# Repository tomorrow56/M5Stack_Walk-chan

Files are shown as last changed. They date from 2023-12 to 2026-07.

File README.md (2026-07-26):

# M5Stack_Walk-chan

A bipedal robot built with M5Stack.

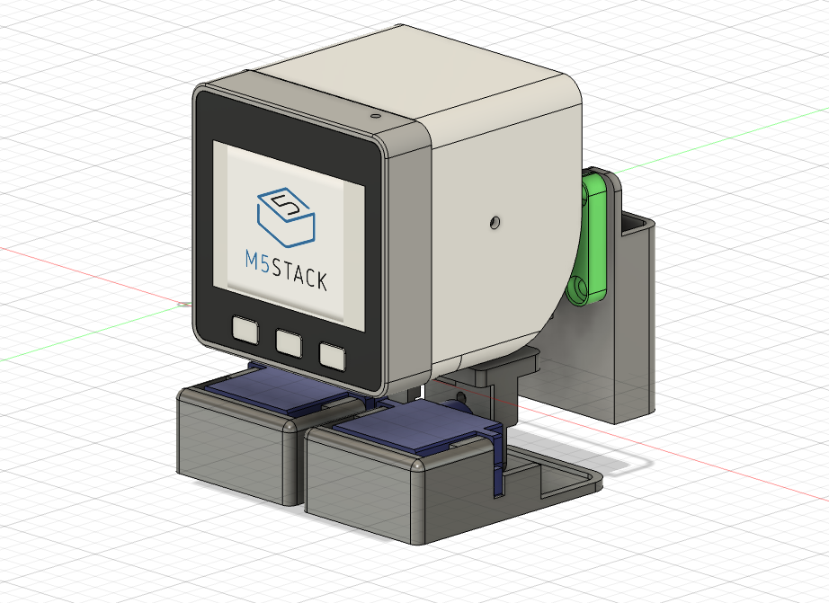
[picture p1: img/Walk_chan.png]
Walk-chan


## Overview

M5Stack Walk-chan（以下、Walk-chan）は、M5Stack を制御ボードとして使った2足歩行ロボットです。Otto DIY のような小型2足歩行ロボットを M5Stack サイズで実現することを目指し、2022年の「ｽﾀｯｸﾁｬﾝ（Stack-chan）」誕生1周年の誕生日会にあわせて設計されました。

このタイプの2足歩行ロボットで重要となるのは、片足を上げた際に接地している足側へ重心を確実に移すことです。M5Stack 本体だけでは重心移動が不十分なため、背面に搭載したバッテリーを左右に動かす直動機構を追加しています。これにより、安定した歩行動作を実現しています。

詳細な制作背景や動作動画については、note 記事「[二足歩行ｽﾀｯｸﾁｬﾝ(Walk chan)を作ってみた](https://note.com/tomorrow56/n/nf83f81b76e1e)」を参照してください。

## Features

- M5Stack 搭載の2足歩行ロボット
- 重心移動用のバッテリー直動機構（ラック＆ピニオン）
- サーボモータ SG90 を計5個使用
- M5Stack の M-Bus からサーボ PWM 用コネクタへ変換する基板同梱
- 3D プリント用 STL ファイルとアセンブリ済み STEP 形式のボディデータ
- Arduino IDE / PlatformIO 向けサンプルスケッチ
- LCD 上にアバター（目）を表示し、歩行と連動した演出が可能

## Hardware

### Required Parts

| 部品 | 数量 | 備考 |
|---|---|---|
| M5Stack Basic / Gray / Fire など | 1 | 制御ボード |
| SG90 互換サーボ | 5 | 2足（脚・足首）+ バッテリー移動用 |
| M5Stack Walk-chan 用基板 | 1 | 本リポジトリの `pcb/` 参照 |
| 3D プリント部品 | 一式 | `3Ddata/stl/` を参照 |
| リチウムイオン電池（NP-40 等） | 1 | コンパクトデジカメ用バッテリー推奨 |
| M3 ビス・ナット | 適量 | ギアガイドなどに使用 |

### Servo Assignment

サンプルスケッチでは、以下のように GPIO とサーボを割り当てています。

| サーボ | GPIO | LEDC チャンネル | 役割 |
|---|---|---|---|
| FootR  | 2 | 0 | 右足首（左右傾き） |
| FootL  | 12 | 1 | 左足首（左右傾き） |
| LegR | 0 | 2 | 右脚（前後スイング） |
| LegL | 15 | 3 | 左脚（前後スイング） |
| Ballast| 13 | 4 | バッテリー重心移動 |

サーボの中心位置や可動範囲は、個体差や組み立て状態に応じてスケッチ内の `cent*` 定数や `rot*` 定数を調整してください。

## 3D Model

ボディ部品の 3D データは `3Ddata/` に格納されています。

- `Walk-chan_assembled.step`：アセンブリ済みの STEP 形式ファイル（Fusion360 などで編集可能）
- `stl/`：3D プリント用の分割 STL ファイル
  - `bracket_front.stl`, `bracket_rear.stl`：前後ブラケット
  - `foot_l.stl`, `foot_r.stl`：左右の足
  - `joint_l.stl`, `joint_r.stl`：左右の脚関節
  - `gear.stl`, `rack_gear.stl`, `gear_guide.stl`：バッテリー直動機構用ギア
  - `holder_NP-40.stl`：NP-40 バッテリーホルダー
  - `shell.stl`：外装シェル

**注意：** 組み立て手順書は作成に至っていないため、現状ではアセンブリ済みの STEP ファイルを CAD で確認しながら組み立ててください。各部品の干渉やサーボの取り付け方向に注意してください。

## PCB for SG90

M5Stack の M-Bus からサーボ用 PWM コネクタに変換する基板データを `pcb/` に同梱しています。

- [gerber](pcb/gerver/)
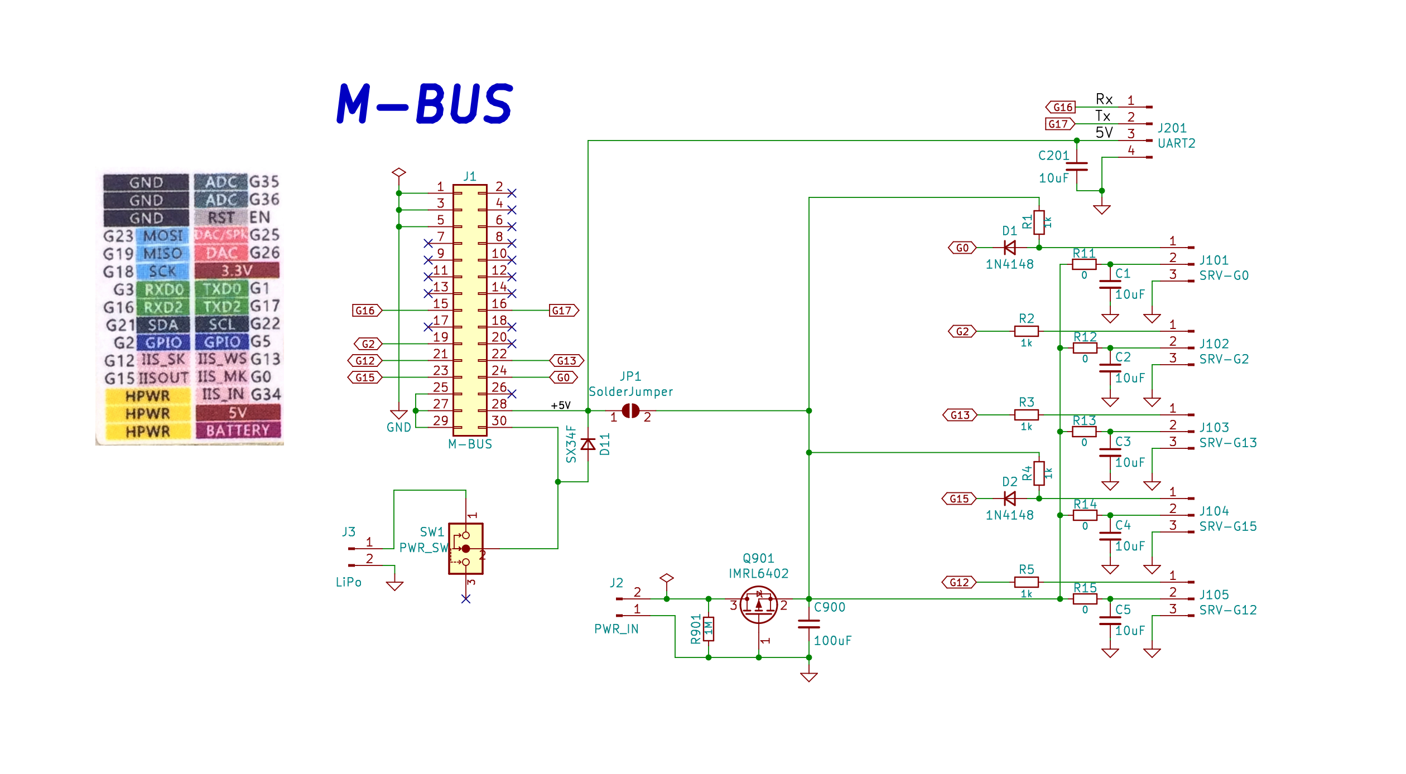
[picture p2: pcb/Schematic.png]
Schematic
- 

### 基板の主な仕様

- M5Stack の M-Bus コネクタから直接各サーボの PWM 信号を出力
- サーボ制御 IC は使用せず、M5Stack の GPIO / LEDC 出力で直接駆動
- Grove 互換コネクタを引き出し、外部センサー等の拡張が可能
- サーボ電源は「コネクタから供給」または「M-Bus の 5V から供給」をハンダジャンパで選択可能
- 2pin ピンヘッダで「サーボ用 5V 電源」と「M5Stack 用リチウムイオン電池」を接続可能
- 横面の物理スイッチで M5Stack 本体の電源 ON/OFF が可能

## Sample Code

サンプルスケッチは `examples/M5_walk-chan_WalkTest/` に格納されています。

- `M5_walk-chan_WalkTest.ino`：メインスケッチ。歩行シーケンスとアバター表示、電池残量・充電状態の監視を行います。
- `clappyavator.h` / `clappyavator.cpp`：M5Stack の LCD に表示するアバター（目）を描画するライブラリ。
- `ip5306.h`：M5Stack 内蔵の電源管理 IC（IP5306）のレジスタ定義。

### 歩行シーケンスの概要

1. バラスト（バッテリー）を左右に移動し、重心を支持脚側へ移す。
2. 支持脚側の足首を内側・遊脚側の足首を外側に傾け、体を傾ける。
3. 遊脚の脚を前後に振り出す。
4. 足首を元に戻し、遊脚を地面に降ろす。
5. 反対側も同様に繰り返し、歩行を継続する。

`setup()` 内では上記の初期動作を1サイクル実施した後、`loop()` 内で左右交互に歩行動作を繰り返します。

### 充電モード

電源投入時に IP5306（0x75）が検出され、かつ充電中の場合は「HOME POSITION」調整モードに移行します。ボタン B を押すと通常の歩行デモに切り替わります。充電中にサーボが動作すると電源負荷や動作不安定の原因になるため、この安全機能が入っています。

## Build and Flash

1. 必要な部品を用意し、3D プリント部品を印刷します。
2. STEP ファイルまたは STL ファイルを参考に、サーボ・ギア・バッテリーを組み込みます。
3. 基板を製造・はんだ付けし、M5Stack と各サーボを接続します。
4. Arduino IDE または PlatformIO で `M5_walk-chan_WalkTest` を開き、M5Stack 向けにビルド・書き込みします。
   - 必要ライブラリ：`M5Stack` ライブラリ
5. 電源を入れ、M5Stack の LCD にアバターが表示され、Walk-chan が歩き始めることを確認します。

## Notes

- 基板のサーボコネクタはブラケットと干渉しない位置に配置されています。コネクタの向きに注意して配線してください。
- バッテリーケースはラックギヤにビスで固定されています。現在は NP-40 型のリチウムイオン電池用ホルダーが同梱されていますが、ケースを差し替えることで単4 乾電池など他の電源にも置き換え可能です。
- バッテリーの左右移動機構はブラケットにはめ込んだ交換可能な構造になっています。
- 2足歩行ロボットのため、床面やバランスによっては転倒することがあります。初動作時は周囲に十分なスペースをとり、低速で確認してください。

## References

- [note: 二足歩行ｽﾀｯｸﾁｬﾝ(Walk chan)を作ってみた](https://note.com/tomorrow56/n/nf83f81b76e1e)
- [Printables: M5Stack Walk-chan](https://www.printables.com/model/687241-m5stack-walk-chan)
- [tomorrow56 (ThousanDIY)](https://note.com/tomorrow56)

## License

[MIT License](LICENSE)

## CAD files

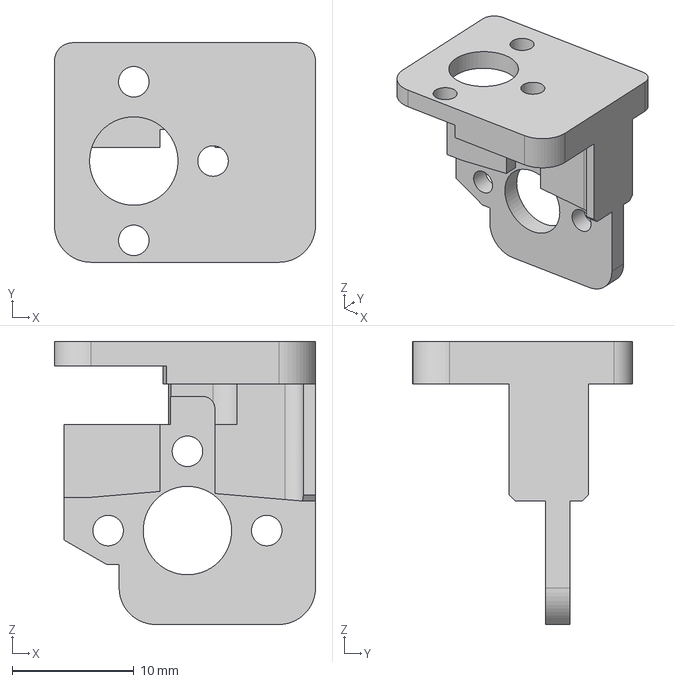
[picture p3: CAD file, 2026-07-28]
3Ddata/step/Joint-L.step
21.4 x 18.0 x 23.2 mm

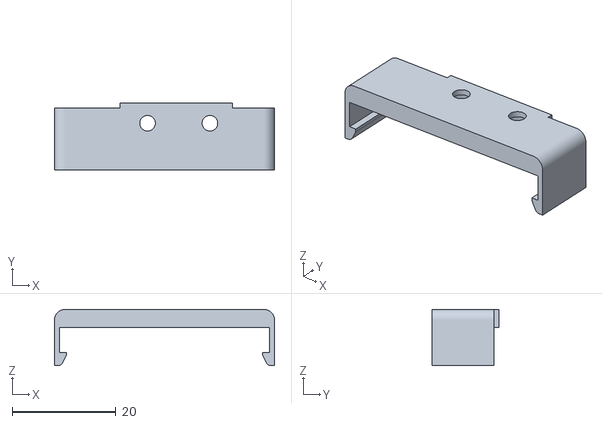
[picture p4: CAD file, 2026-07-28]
3Ddata/stl/Guide.stl
42.3 x 12.9 x 10.8

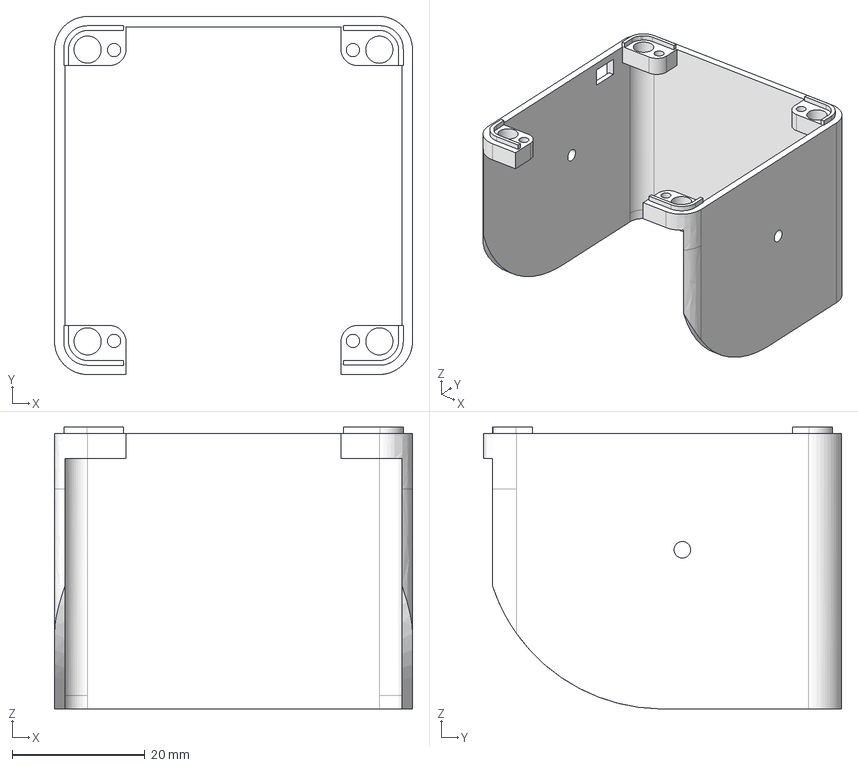
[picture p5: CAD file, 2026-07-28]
3Ddata/step/shell.step
54.0 x 54.0 x 42.5 mm

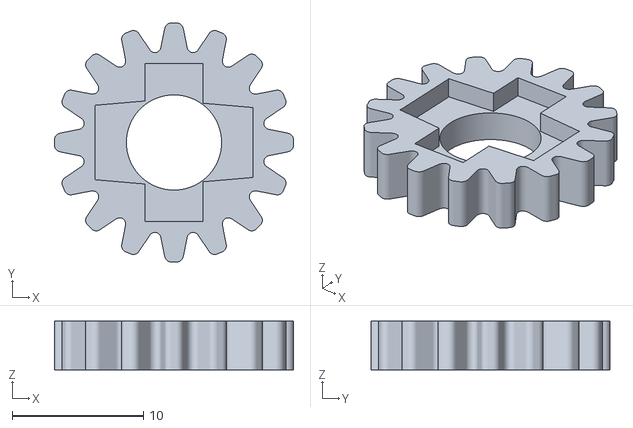
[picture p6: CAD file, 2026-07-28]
3Ddata/stl/gear.stl
18.2 x 18.2 x 3.70

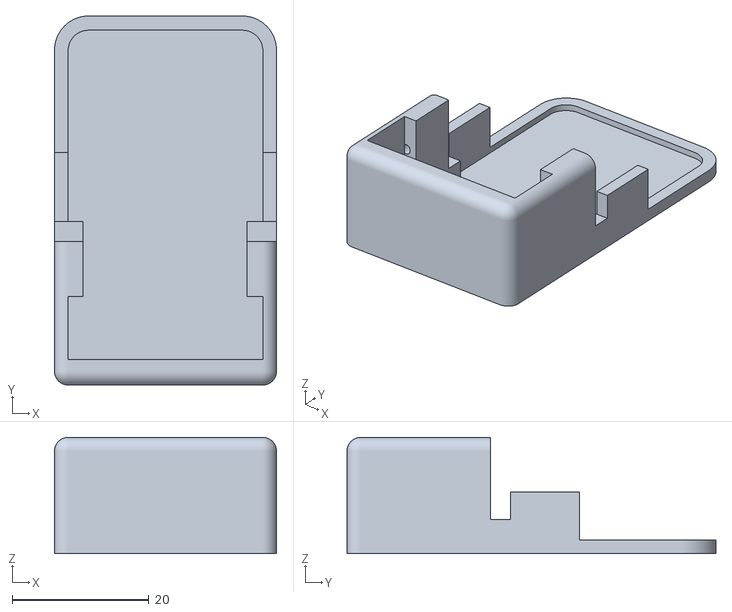
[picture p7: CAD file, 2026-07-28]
3Ddata/stl/foot_1.stl
32.5 x 54.0 x 17.0

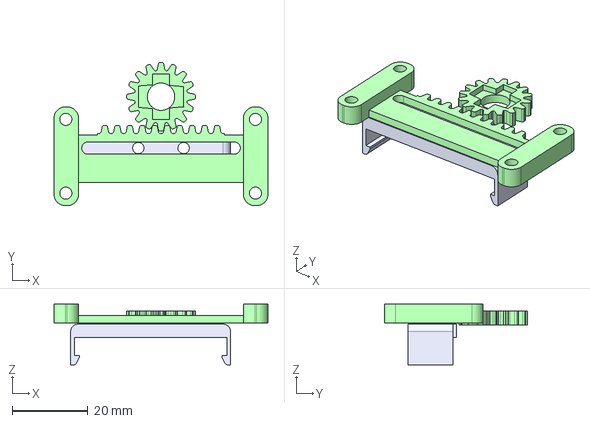
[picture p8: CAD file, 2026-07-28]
3Ddata/step/Servo_Linear.step
56.6 x 38.0 x 16.1 mm

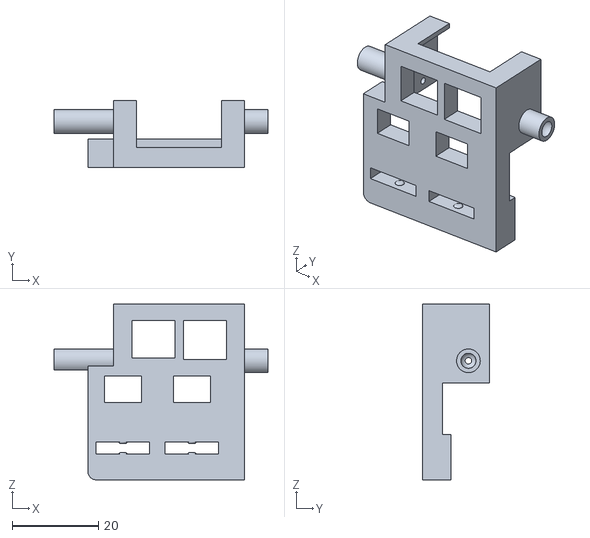
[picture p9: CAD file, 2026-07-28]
3Ddata/stl/bracket_front.stl
49.6 x 15.7 x 40.8

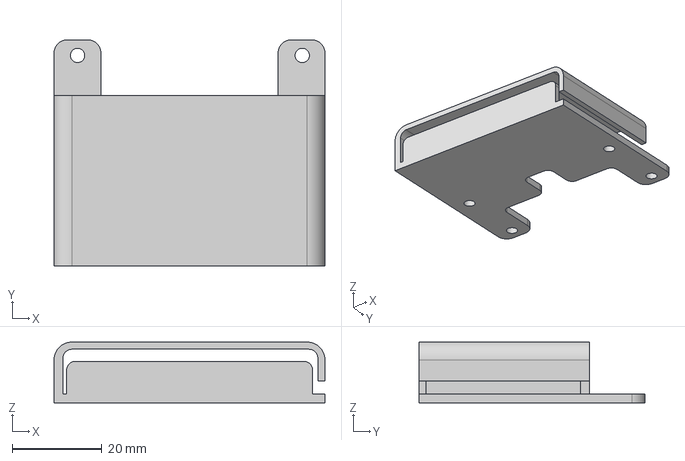
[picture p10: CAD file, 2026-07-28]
3Ddata/step/holder_NP-40.step
60.6 x 50.6 x 13.6 mm

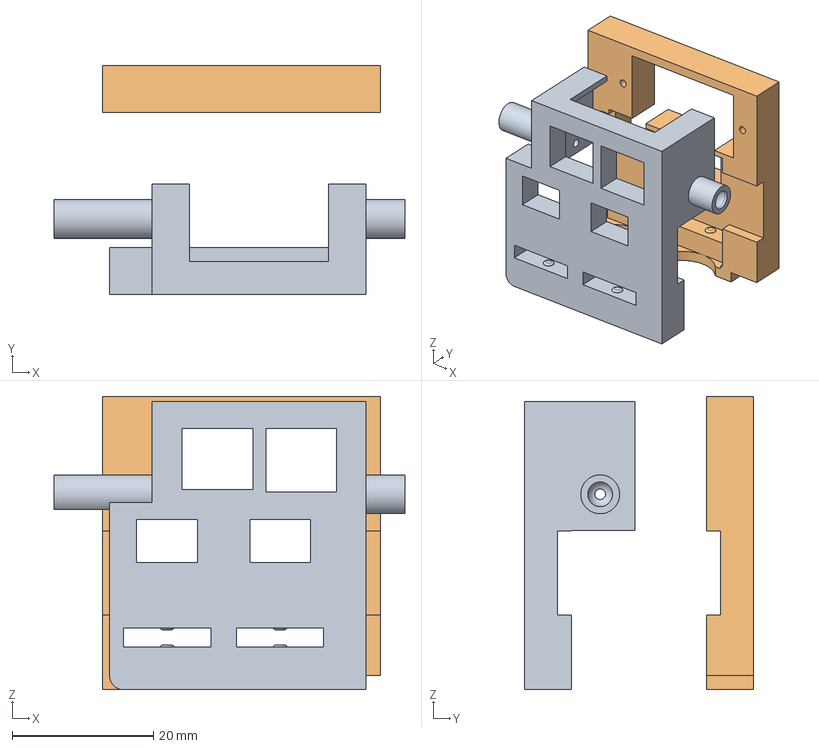
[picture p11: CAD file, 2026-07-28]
3Ddata/step/bracket_SG90.step
49.7 x 32.4 x 41.5 mm

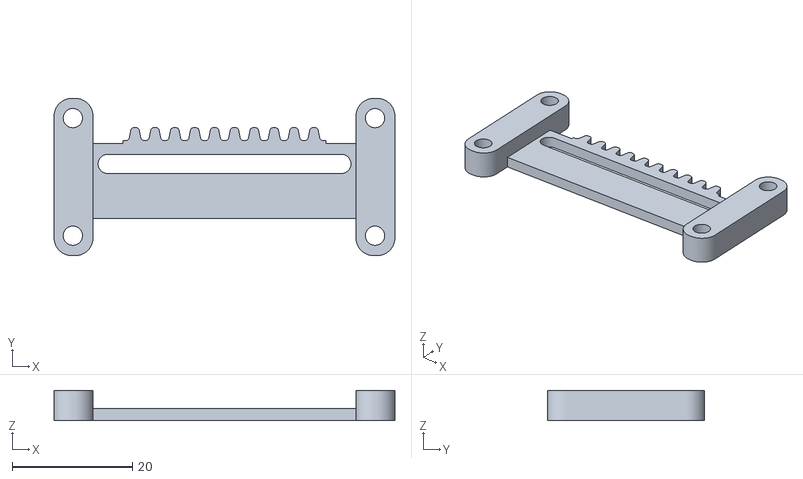
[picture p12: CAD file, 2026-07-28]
3Ddata/stl/RackGear.stl
56.6 x 26.1 x 5.00

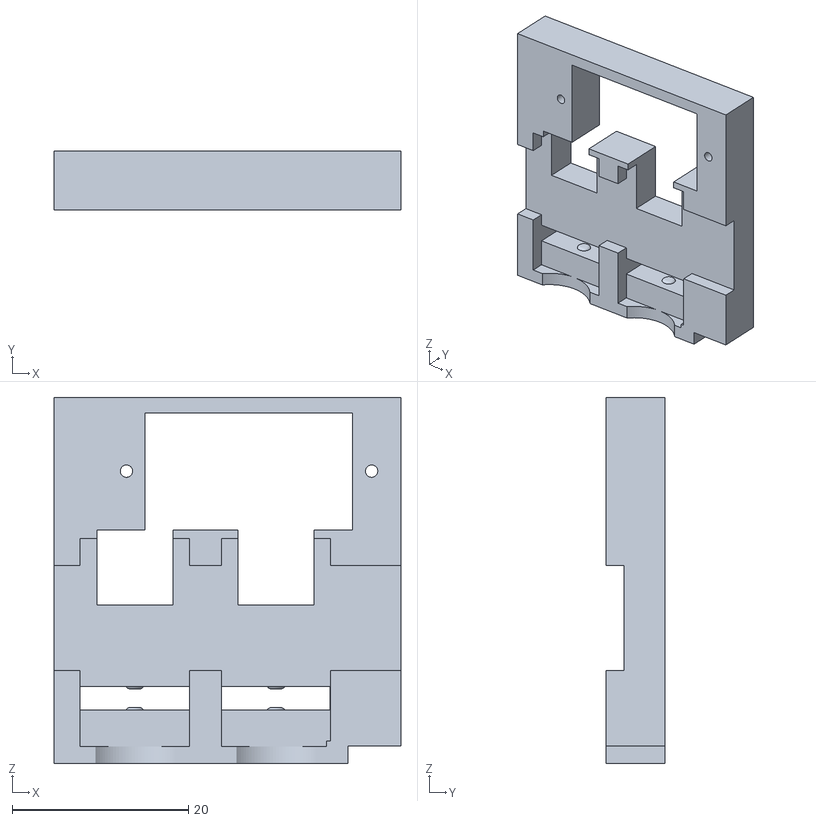
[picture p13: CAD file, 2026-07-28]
3Ddata/stl/bracket_rear.stl
39.3 x 6.65 x 41.5

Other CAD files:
3Ddata/step/Joint-R.step
3Ddata/step/foot.step
3Ddata/stl/Joint-L.stl
3Ddata/stl/Joint-R.stl
3Ddata/stl/holder_NP-40.stl
3Ddata/stl/shell.stl

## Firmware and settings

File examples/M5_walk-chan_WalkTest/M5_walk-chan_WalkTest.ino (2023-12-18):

#include <M5Stack.h>
#include "M5StackUpdater.h"
#include "ip5306.h"

#include "clappyavator.h"

Avator *avator;

#define chgDET

int pos1 = 0;
int pos2 = 0;

/********************************
* for Servo control
*********************************/
const uint8_t motorInterval = 30;  //[ms]

#define LEDC_CHANNEL_0  0  // channel of 16 channels (started from zero)
#define LEDC_TIMER_BIT 12  // use 12 bit precission for LEDC timer
#define LEDC_BASE_FREQ 50  // use 50 Hz as a LEDC base frequency

// Servo Range
// int srvMin = 103; // (103/4096)*20ms ≒ 0.5 ms (-90°)
// int srvMax = 491; // (491/4096)*20ms ≒ 2.4 ms (+90°)
#define srvMin 105
#define srvMax 475

// Servo assign to each channel
#define pinFootR 2   // foot
#define channelFootR 0
#define pinFootL 12
#define channelFootL 1

#define pinlegR 0   // leg
#define channelLegR 2
#define pinLegL 15
#define channelLegL 3

#define pinBallast 13 // battery
#define channelBallast 4

// center position calibration(0-180 deg)
const int centFootR = 110;
const int centFootL = 100;

const int centLegR = 80;
const int centLegL = 95;

const int centBallast = 83;

const int rotFoot = 15;
const int rotLeg = 30;
const int rotBallast = 75;

int smooth = 5;
int stepInterval = 100;

void initServo(int pinServo, int ledc_channel) { 
  // init Servo
  // Setup timer and attach timer to a servo pin
  // ledcSetup(LEDC_CHANNEL_0, LEDC_BASE_FREQ, LEDC_TIMER_BIT);
  ledcSetup(ledc_channel, LEDC_BASE_FREQ, LEDC_TIMER_BIT);

  // ledcAttachPin(Servo_PIN1, LEDC_CHANNEL_0);
  ledcAttachPin(pinServo, ledc_channel);
  ledcWrite(ledc_channel, 0);
}

// Angle 0 - 180 degree
void setSrvAngle(int channelServo, int degree){
  float stepDegree = (srvMax - srvMin) / 180;
  ledcWrite(channelServo, srvMin + ((int)stepDegree * degree));
}

/*
 * Update Avator
 */
void avatorUpdate(void* arg) {
  int cnt = 0;
  while (1) {
    if(cnt == 0){
      //avator->openMouth(15);
    }
    if (cnt % 100 == 97){
      avator->openEye(false);
    }
    if (cnt % 100 == 0){
      avator->openEye(true);
      cnt = random(100);
    }
    cnt++;
    vTaskDelay(50);
  }
}

void setup() {

// M5Stack::begin(LCDEnable, SDEnable, SerialEnable, I2CEnable);
  M5.begin(true, true, true, true);

  M5.Power.begin();
  M5.Power.setVinMaxCurrent(CURRENT_100MA);

  M5.Speaker.begin();
  M5.Speaker.mute();
  M5.Speaker.end();

  if(digitalRead(BUTTON_A_PIN) == 0) {
    Serial.println("Will Load menu binary");
    updateFromFS(SD);
    ESP.restart();
  }

  Serial.println("M5Walk-chan direct servo version");

  M5.Lcd.setBrightness(64);
  M5.Lcd.setTextColor(WHITE, BLACK);
  M5.Lcd.setTextSize(2);
  M5.Lcd.setCursor(0, 0);

  avator = new Avator();
  M5.Lcd.fillScreen(SECONDARY_COLOR);

  // Servo initialization
  initServo(pinFootR, channelFootR);
  initServo(pinFootL, channelFootL);
  initServo(pinlegR, channelLegR);
  initServo(pinLegL, channelLegL);
  initServo(pinBallast, channelBallast);

 /*
 * Demo action
 */
  setHomePosi();
  
  delay(1000);

  #ifdef chgDET
    if(checkI2C(0x75)){
      Serial.print("IP5306-I2C found!");
      if(getChargeEnable()){
        adjMode();
      }
    }else{
        Serial.print("IP5306-I2C not found!");
    }
  #endif

  avator->init();

  // xTaskCreatePinnedToCore(タスクの関数名,"タスク名",スタックメモリサイズ,NULL,タスク優先順位,タスクハンドルポインタ,Core ID);
  // xTaskCreatePinnedToCore(func,"name",Stuck size,NULL,priority,Task pointer,Core ID)
  // Core ID: 0 or 1 or tskNO_AFFINITY
  xTaskCreatePinnedToCore(avatorUpdate, "Task0", 4096, NULL, 1, NULL, 0);

//  checkServo();

// Walking test
//--- 左ステップ ---
// バラストを左へ移動
  for(int j = 0; j < rotBallast; j++){
    setBallast(j);
    delay(smooth);
  }

  delay(stepInterval);

// 左側外へ倒す
  for(int j = 0; j < rotFoot; j++){
    setFootL(j);
    delay(10);
    setFootR(-1 * j);
    delay(smooth);
  }

  delay(stepInterval);

// 右足を前に出す
  for(int j = 0; j < rotLeg; j++){
    setLegL(-1 * j);
    delay(10);
    setLegR(j);
    delay(smooth);
  }

  delay(stepInterval);

// 右足を下ろす
  for(int j = rotFoot; j >= 0; j--){
    setFootL(j);
    delay(10);
    setFootR(-1 * j);
    delay(smooth);
  }

  delay(stepInterval);

//****** ここから繰り返し *****
//****** 右ステップ *****
// バラストを右へ移動
  for(int j = rotBallast; j >= -1 * rotBallast; j--){
    setBallast(j);
    delay(smooth);
  }

  delay(stepInterval);

// 右足を外へ倒す
  for(int j = 0; j < rotFoot; j++){
    setFootR(j);
    delay(10);
    setFootL(-1 * j);
    delay(smooth);
  }

  delay(stepInterval);

// 左足を前に出す
    for(int j = rotLeg; j >= -1 * rotLeg; j--){
      setLegL(-1 * j);
      delay(10);
      setLegR(j);
      delay(smooth);
    }

    delay(stepInterval);

// 左足を下ろす
    for(int j = rotFoot; j >= 0; j--){
      setFootR(j);
      delay(10);
      setFootL(-1 * j);
      delay(smooth);
    }

    delay(stepInterval);

//****** 左ステップ *****
// バラストを左へ移動
  for(int j = -1 * rotBallast; j < rotBallast; j++){
    setBallast(j);
    delay(smooth);
  }

  delay(stepInterval);

// 左足を外へ倒す
  for(int j = 0; j < rotFoot; j++){
    setFootL(j);
    delay(10);
    setFootR(-1 * j);
    delay(smooth);
  }

  delay(stepInterval);

// 右足を前に出す
  for(int j = -1 * rotLeg; j < rotLeg; j++){
    setLegL(-1 * j);
    delay(10);
    setLegR(j);
    delay(smooth);
  }

    delay(stepInterval);

// 右足を下ろす
  for(int j = rotFoot; j >= 0; j--){
    setFootL(j);
    delay(10);
    setFootR(-1 * j);
    delay(smooth);
  }

  delay(stepInterval);

}

void loop(){

//****** ここから繰り返し *****
//****** 右ステップし *****
// バラストを右へ移動
  for(int j = rotBallast; j >= -1 * rotBallast; j--){
    setBallast(j);
    delay(smooth);
  }

  delay(stepInterval);

// 右側外へ倒す
  for(int j = 0; j < rotFoot; j++){
    setFootR(j);
    delay(10);
    setFootL(-1 * j);
    delay(smooth);
  }

  delay(stepInterval);

// 左足を前に出す
  for(int j = rotLeg; j >= -1 * rotLeg; j--){
     setLegL(-1 * j);
    delay(10);
    setLegR(j);
    delay(smooth);
  }

  delay(stepInterval);

// 左足を下ろす
  for(int j = rotFoot; j >= 0; j--){
    setFootR(j);
    delay(10);
    setFootL(-1 * j);
    delay(smooth);
  }

  delay(stepInterval);

//****** 左ステップ *****
// バラストを左へ移動
  for(int j = -1 * rotBallast; j < rotBallast; j++){
    setBallast(j);
    delay(smooth);
  }

  delay(stepInterval);

// 左足を外へ倒す
  for(int j = 0; j < rotFoot; j++){
    setFootL(j);
    delay(10);
    setFootR(-1 * j);
    delay(smooth);
  }

  delay(stepInterval);

// 右足を前に出す
  for(int j = -1 * rotLeg; j < rotLeg; j++){
    setLegL(-1 * j);
    delay(10);
    setLegR(j);
    delay(smooth);
  }

  delay(stepInterval);

// 右足を下ろす
  for(int j = rotFoot; j >= 0; j--){
    setFootL(j);
    delay(10);
    setFootR(-1 * j);
    delay(smooth);
  }

  delay(stepInterval);
}

// Home position
void setHomePosi(){
  setBallast(0);
  delay(stepInterval);
  setFootR(0);
  delay(stepInterval);
  setFootL(0);
  delay(stepInterval);
  setLegR(0);
  delay(stepInterval);
  setLegL(0);
}

// Servo Check
void checkServo(){
  Serial.println("Ballast test");
  setBallast(0);
  delay(500);
  setBallast(30);   // Left
  delay(500);
  setBallast(-30);  // Right
  delay(500);
  setBallast(0);
  delay(500);

  Serial.println("Right foot test");
  setFootR(0);
  delay(500);
  setFootR(10);   // Out
  delay(500);
  setFootR(-10);  // In
  delay(500);
  setFootR(0);
  delay(500);

  Serial.println("Lest foot test");
  setFootL(0);
  delay(500);
  setFootL(10);   // Out
  delay(500);
  setFootL(-10);  // In
  delay(500);
  setFootL(0);
  delay(500);

  Serial.println("Right leg test");
  setLegR(0);
  delay(500);
  setLegR(10);   // Out
  delay(500);
  setLegR(-10);  // In
  delay(500);
  setLegR(0);
  delay(500);

  Serial.println("Left leg test");
  setLegL(0);
  delay(500);
  setLegL(10);   // Out
  delay(500);
  setLegL(-10);  // In
  delay(500);
  setLegL(0);
  delay(500);
}

/*************************************************** 
 Motion Control
 画面正面から見た状態で左右を定義
 **************************************************/

// Ballast +:Left, -: Right
void setBallast(int angle){
  setSrvAngle(channelBallast, centBallast + angle);
}

// Right Foot +:Out, -: In
void setFootR(int angle){
  setSrvAngle(channelFootR, centFootR + angle);
}

// Left Foot +:Out, -: In
void setFootL(int angle){
  setSrvAngle(channelFootL, centFootL - angle);
}

// Right Leg +:Out, -: In
void setLegR(int angle){
  setSrvAngle(channelLegR, centLegR - angle);
}

// Left Leg +:Out, -: In
void setLegL(int angle){
  setSrvAngle(channelLegL, centLegL + angle);
}

/*************************************************** 
 status of charging
 **************************************************/
void adjMode(){
    delay(300);
    M5.Lcd.fillScreen(BLACK);
    M5.Lcd.setTextSize(3);
    M5.Lcd.setTextColor(WHITE, BLACK);
    M5.Lcd.setCursor(50, 0);
    M5.Lcd.print("HOME POSITION");
    setHomePosi();

    while(1){
      M5.update();
      M5.Lcd.setCursor(10, 150);
      if(getChargeEnable()){
        switch(getChargeMode()){
          case 1:
            M5.Lcd.print("  Full Charge     ");
            break;
          case 2:
            M5.Lcd.print("Charging(CV mode) ");
            break;
          case 3:
            M5.Lcd.print("Charging(CC mode) ");
            break;
          default:
            M5.Lcd.print("  Unknown mode    ");
            break;
        }
      }else{
        M5.Lcd.print("                     ");
      }

      uint8_t Level =  M5.Power.getBatteryLevel();
      if(Level > 100){
        Level = 100;
      }else if(Level < 0){
        Level = 0;
      }
      M5.Lcd.progressBar(30, 200, 260, 20, Level);
      M5.Lcd.drawRect(29, 199, 262, 22, WHITE);

      if(M5.BtnB.wasPressed()){
        M5.Lcd.fillScreen(SECONDARY_COLOR);
        avator->init();
        break;
      }
      delay(100);
   }
}

boolean checkI2C(byte address){
  Wire.beginTransmission(address);
  byte error;
  error = Wire.endTransmission();
  if(error == 0){
    return true;
  }else{
    return false;
  }
}

boolean getChargeEnable(){
  uint8_t data;
  M5.I2C.readByte(IP5306_ADDR, IP5306_REG_READ0, &data);
  return((data & CHARGE_ENABLE_BIT) == 0x08);
}

uint8_t getChargeMode(){
  uint8_t data;
  M5.I2C.readByte(IP5306_ADDR, IP5306_REG_READ1, &data);

  if((data & CHARGE_FULL_BIT)){
//    Serial.println("CHARGE_FULL");
    return 1;
  }else if((data & 0xE0) == CHARGE_MODE_CV){
//    Serial.println("CHARGE_MODE_CV");
    return 2;
  }else if((data & 0xE0) == CHARGE_MODE_CC){
//    Serial.println("CHARGE_MODE_CC");
    return 3;
  }else{
//    Serial.println("CHARGE_MODE_Unknown");
    return 0;
  }
}

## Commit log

2026-07-15 Add Printables section with link
2026-07-26 Document Walk-chan details from the note article and add macOS gitignore
    - Expand README with overview, features, hardware parts, servo GPIO
    assignments, 3D model/PCB descriptions, sample code walkthrough,
    build instructions, and notes based on the note article
    - Add .gitignore to exclude macOS resource forks, .DS_Store, and
    editor/IDE artifacts
    Generated with [Devin](https://devin.ai)
2026-07-28 Update 3D model data (STL/STEP) with revised parts
    - Re-export assembled STEP file with updated part/component naming
    - Add per-part STEP files under 3Ddata/step/
    - Rename/replace foot, joint, and rack gear STL parts
    (foot_1/foot_2, Joint-L/Joint-R, RackGear, Guide)
    - Update bracket, gear, holder, and shell STL geometry
    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
    [Guide.stl, Joint-L.step, Joint-L.stl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]
